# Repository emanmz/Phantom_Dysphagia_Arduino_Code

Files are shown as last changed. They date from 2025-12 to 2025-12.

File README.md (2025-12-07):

## ⚙️ README: Linear Actuator Control Code

This README provides an overview and instructions for the Arduino code used to control two stepper-motor-driven linear actuators. This is includes multiple files:
Linear_Actuator_Code_2_Change_negative_or_positive
Linear_Actuator_Code_with_Calibration
Rail_to_Arduino_DAQ
Adams_Apple_Movement.py
Linear_Regression.py

## 1st **Code File:** (Implied: `Linear_Actuator_Code_2_Change_negative_or_positive.ino`)

-----

## ⚠️ WARNING: Free Use / Uncalibrated Mode

This code is designed for "free use," allowing absolute positioning of the actuators without applying calibration coefficients.

  * **DANGER:** Use caution. The position commands directly translate to motor steps, meaning if the physical system is not homed or if the motor loses steps, the reported position will be incorrect, potentially leading to the actuator hitting its physical end stops.
  * **Recommendation:** Only use this code if you fully understand the mechanics and stepper motor operation.

-----

## 📌 Actuator & Axis Definitions

This system uses standard CNC-style axis naming conventions:

| Axis | Actuator | Movement | Pins | Position Range |
| :--- | :--- | :--- | :--- | :--- |
| **Z** | Horizontal | Forward & Backwards | `dirPinH` (2), `stepPinH` (3) | **Negative and Positive** |
| **Y** | Vertical | Up & Down | `dirPinV` (9), `stepPinV` (8) | **Negative and Positive** |

-----

## 🚀 How to Use (Serial Interface)

The code runs in a continuous loop, monitoring the Serial Monitor for position and speed commands.

### 1\. Startup

1.  Connect the Arduino to the PC and open the **Serial Monitor** at **9600 baud**.
2.  The system will output: `Ready. Send input as: z_mm,z_mmps,vert_mm,vert_mmps`

### 2\. Sending Commands

Commands must be sent in the following comma-separated format:

```
z_mm,z_mmps,vert_mm,vert_mmps
```

| Parameter | Description | Units | Range |
| :--- | :--- | :--- | :--- |
| **`z_mm`** | Target absolute position for the **Z (Horizontal)** axis. | mm | Constrained by `min_position_mm_z` (e.g., -5.0) and `max_position_mm_z` (e.g., 25.0). |
| **`z_mmps`** | Desired speed for the **Z (Horizontal)** axis. | mm/s | Constrained to **5.0 to 25.0 mm/s**. |
| **`vert_mm`** | Target absolute position for the **Y (Vertical)** axis. | mm | Constrained by `min_position_mm_vertical` (e.g., -5.0) and `max_position_mm_vertical` (e.g., 100.0). |
| **`vert_mmps`**| Desired speed for the **Y (Vertical)** axis. | mm/s | Constrained to **20.0 to 80.0 mm/s**. |

**Example Command:**

To move the Z-axis to 10.0 mm at 15 mm/s and the Vertical (Y) axis to 50.0 mm at 40 mm/s, send:

```
10.0,15,50.0,40
```

-----

## 🛠️ Key Code Settings

The main configurable values are located at the top of the file under `PIN & SETTINGS`.

### Horizontal (Z) Settings

| Constant | Value | Description |
| :--- | :--- | :--- |
| `steps_per_mm_horizontal` | `613.50` | The physical steps required for 1 mm of Z-axis travel. **Crucial for accuracy.** |
| `max_position_mm_z` | `25.00` | Max positive position allowed for Z (soft limit). |
| `min_position_mm_z` | `-5.0` | Max negative position allowed for Z (soft limit). |

### Vertical (Y) Settings

| Constant | Value | Description |
| :--- | :--- | :--- |
| `steps_per_mm_vertical` | `555.56` | The physical steps required for 1 mm of Y-axis travel. **Crucial for accuracy.** |
| `max_position_mm_vertical` | `100.0` | Max positive position allowed for Y (soft limit). |
| `min_position_mm_vertical` | `-5.0` | Max negative position allowed for Y (soft limit). |

-----

## 💻 Core Functions

### `moveBoth(float zMM, float zSpeed_mmps, float vertMM, float vertSpeed_mmps)`

  * **Purpose:** Moves both actuators simultaneously to the absolute target positions specified by `zMM` and `vertMM`.
  * **Logic:**
    1.  Calculates the required **target steps** (`targetH`, `targetV`) by multiplying the input `mm` by the respective `steps_per_mm`.
    2.  Calculates the **delta steps** (`deltaH`, `deltaV`) needed from the current position.
    3.  Determines the direction (`dirH`, `dirV`) based on whether the target step count is higher or lower than the current step count.
    4.  Calculates the **step delay** from the input speed (`mm/s`).
    5.  Steps both motors in a blocking `while` loop until both reach their respective targets.
    6.  Updates the global position variables (`currentPositionStepsH`, `currentPositionStepsV`).

## 2nd Code: Linear_Actuator_Code_with_Calibration Calibrated 2-Axis Actuator Control with LVDT

This code is an Arduino sketch designed for **precise, closed-loop positioning** of two stepper motor actuators (Horizontal/Z and Vertical/Y) by applying **calibration coefficients** derived from an **LVDT (Linear Variable Differential Transformer)** sensor.

-----

## ⚠️ Operation Mode

This code is designed for laboratory or experimental use where the relationship between the commanded motor travel and the real-world measured travel must be continuously corrected.

  * **Axis Naming:**

      * **Horizontal (H) Actuator** = **Z-Axis** (Forward/Backward)
      * **Vertical (V) Actuator** = **Y-Axis** (Up/Down)

  * **Core Function:** It performs two main tasks:

    1.  **Calibration:** Runs routines (`calibrate_z`, `calibrate_y`) to determine the correction factors (slope and offset) between commanded motor movement and the actual movement measured by the LVDT.
    2.  **Movement:** Uses the calculated correction factors to convert a **Desired Real-World position** (`realHorizMM`) into the **necessary Commanded Motor Steps**.

-----

## 🛠️ Key Components & Setup

### 1\. Actuators and Kinematics

| Axis | Pin Settings | Max Position | Steps/mm |
| :--- | :--- | :--- | :--- |
| **Z** (Horizontal) | `dirPinH` (2), `stepPinH` (3) | `25.00 mm` | `613.50` |
| **Y** (Vertical) | `dirPinV` (9), `stepPinV` (8) | `100.0 mm` | `555.56` |

### 2\. LVDT Sensor (Measurement)

The LVDT measures real-world displacement and is critical for calibration.

| Setting | Value | Description |
| :--- | :--- | :--- |
| `LVDT_PIN` | `A0` | Analog Pin for LVDT input (0-1023 bits). |
| `CAL_LVDT_SLOPE_MM_PER_BIT` | `-0.00518` | Slope ($m$) from the LVDT's initial characterization: $mm = m \cdot bit + b$. |
| `CAL_LVDT_INTERCEPT_MM` | `4.84308` | Intercept ($b$) from the LVDT's initial characterization. |
| `LVDT_MAX/MIN_DEFLECTION` | `3.7` / `1.7` | Values used to **filter out bad/unstable readings** during data collection. |

### 3\. Calibration Coefficients

These values are updated after running the calibration routines (`Z` or `Y`). They define the final correction formula:

$$
\text{Real mm} = \text{Slope} \cdot \text{Commanded mm} + \text{Offset}
$$

| Axis | Variable | Initial Value |
| :--- | :--- | :--- |
| **Z** | `cal_slope_z` | `0` |
| **Z** | `cal_offset_z` | `-0.776723` |
| **Y** | `cal_slope_Y` | `1.639743` |
| **Y** | `cal_offset_Y` | `0` |

-----

## ⌨️ Serial Commands

All interaction is done via the **Serial Monitor** at **9600 baud**.

### 1\. Calibration

To initiate a calibration routine:

  * **Z-Axis (Horizontal):** Type `Z`
  * **Y-Axis (Vertical):** Type `Y`

The code will prompt you to confirm with `Ready` before starting the movement and data collection process.

### 2\. Movement (Using Calibration)

To move the actuators to a **real-world desired position** after calibration:

1.  Type `Move` (This simply prints the command format).
2.  Send the position and speed command in the following format:

<!-- end list -->

```
horiz_mm,horiz_speed,vert_mm,vert_speed
```

| Parameter | Description |
| :--- | :--- |
| `horiz_mm` | **Desired Real-World Z position (mm)**. |
| `horiz_speed` | **Z-Axis speed (mm/s)**. |
| `vert_mm` | **Desired Real-World Y position (mm)**. |
| `vert_speed` | **Y-Axis speed (mm/s)**. |

The `moveBoth` function will automatically apply the calculated **`cal_slope`** and **`cal_offset`** to determine the actual steps needed to hit the `realHorizMM` target.

-----

## ⚙️ Core Functionality

### **Core Functionality: `moveBoth(...)`**

* **Correction:** It inverts the calibration equation to find the required motor command using the formula above.
* **Execution:** The motor is then commanded to move to the calculated **Commanded mm** position using a non-blocking step algorithm.

### `moveBoth(...)`

This function handles the main movement using the calibration coefficients.

### **Inverse Calibration Formula**

The `moveBoth` function uses this formula to calculate the necessary motor command:

$$
\text{Commanded mm} = \frac{\text{Desired Real mm} - \text{Offset}}{\text{Slope}}
$$

  * **Execution:** The motor is then commanded to move to the `Commanded mm` position using a non-blocking step algorithm.

### `readLVDT_mm()`

Reads the LVDT sensor, averages **200 analog samples**, applies the LVDT's intrinsic calibration constants, and returns the measured displacement in mm. It uses the `LVDT_MAX/MIN_DEFLECTION` limits to return a sentinel value of `-999.0` for noisy or invalid readings, ensuring only quality data is used for the actuator calibration.

### `linearRegression(...)`

Performs a standard linear fit to calculate the **slope** and **intercept (offset)** based on the collected data points (Commanded vs. Measured positions). This result is stored in the global `cal_slope` and `cal_offset` variables.

This system is a sophisticated **Data Acquisition (DAQ)** platform that controls two linear actuators using pre-determined calibration coefficients and streams real-time LVDT sensor data back to a controlling **Python script** for logging and analysis.

---

#### 3rd & 4th **Code Files:** Calibrated 2-Axis Motion and Data Streaming (Rail\_to\_Arduino\_DAQ & Adams\_Apple\_Movement)

This project consists of two linked files:

1.  **Arduino Code (Rail\_to\_Arduino\_DAQ):** Controls the stepper motors, reads the LVDT, applies calibration corrections for movement, and streams real-time movement data.
2.  **Python Code (`Adams_Apple_Movement.py`):** Acts as the **Host Controller** to send movement commands to the Arduino and captures the streaming data into a CSV log file.

---

## 📌 Actuator & Axis Definitions

This system uses a horizontal actuator (Z) and a vertical actuator (Y).

| Axis | Actuator | Movement | Max Position (Commanded) |
| :--- | :--- | :--- | :--- |
| **H / X-Axis** | Horizontal | Forward & Backwards | `25.00 mm` |
| **V / Y-Axis** | Vertical | Up & Down | `100.0 mm` |

### Calibration Model

The core of the movement logic is the **inverse calibration** applied in the `moveBoth` function:

$$
\text{Commanded mm} = \frac{\text{Desired Real mm} - \text{Offset}}{\text{Slope}}
$$

This equation correctly solves for the necessary motor command to achieve the $\text{Desired Real mm}$ based on the calculated $\text{Slope}$ and $\text{Offset}$ coefficients.
| Axis | Coefficient | Value | Description |
| :--- | :--- | :--- | :--- |
| **X (H)** | `cal_slope_X` | `0.900650` | Slope correction for horizontal travel. |
| **X (H)** | `cal_offset_X` | `-0.776723` | Offset correction for horizontal travel. |
| **Y (V)** | `cal_slope_Y` | `1.639743` | Slope correction for vertical travel. |
| **Y (V)** | `cal_offset_Y` | `-1.543572` | Offset correction for vertical travel. |

---

## ⚡️ Arduino Sketch: Motion Control & Data Streaming

The Arduino sketch focuses on executing a movement, applying calibration, and streaming the resulting data over the serial port.

### Key Functionality

1.  **Movement (`moveBoth`):** Accepts **Desired Real-World MM** values, converts them to the required **Commanded Motor MM** using the calibration coefficients, and executes the movement by calculating the necessary steps and timing delays.
2.  **Real-Time Logging:** While the motors are stepping, data is logged every $\mathbf{50}$ **steps** (`LOG\_INTERVAL\_STEPS`). Each line streams:
    * Time (ms)
    * Current Steps (H & V)
    * Commanded MM (H & V, based on steps)
    * Estimated Real MM (H & V, based on calibration)
    * Real LVDT Reading (mm)
3.  **End-of-Move Summary:** After the motion is complete and the LVDT is sampled at the final position, a summary block is printed, demarcated by `#MOVE_CALC_DATA_START` and `#MOVE_CALC_DATA_END`. This allows the Python script to easily isolate the final, definitive data points for a single move.
4.  **Homing:** After every `moveBoth` command, the code immediately calls `moveBoth_Without_Calib(0, horizSpeed, 0, vertSpeed)` to **return the actuators to the zero position**.

---

## 🐍 Python Host Script: Data Acquisition (DAQ)

The Python script manages the experiment sequence, sends commands, and captures all serial output, separating the streaming data from the summary data.

### Configuration

* **`ARDUINO_PORT`:** Must be changed to match your Arduino's serial port (e.g., `'COM3'` on Windows, `'/dev/ttyACM0'` on Linux/Mac).
* **`OUTPUT_CSV_FILE`:** The file name where all real-time stream data will be logged (e.g., `'movement_log6.csv'`).
* **`MOVEMENT_PLAN`:** A list of moves to execute in sequence. Each element is `[realHorizMM, horizSpeed_mmps, realVertMM, vertSpeed_mmps]`.

### Data Logging Logic

The script uses a **state machine** to handle the varying output from the Arduino:

1.  **Stream Data:** All comma-separated lines *outside* the summary block are treated as real-time movement data and are written directly to the CSV file.
2.  **Summary Block:** Lines between `#MOVE_CALC_DATA_START` and `#MOVE_CALC_DATA_END` are read and ignored in the main CSV stream, as they serve as an end-of-move marker for more targeted data extraction if needed.
3.  **Sequence Completion:** The script waits until the Arduino prints a final position report (`"Current Pos V: "`) to confirm the entire sequence (move out + return to zero) is complete before proceeding to the next move in `MOVEMENT_PLAN`.

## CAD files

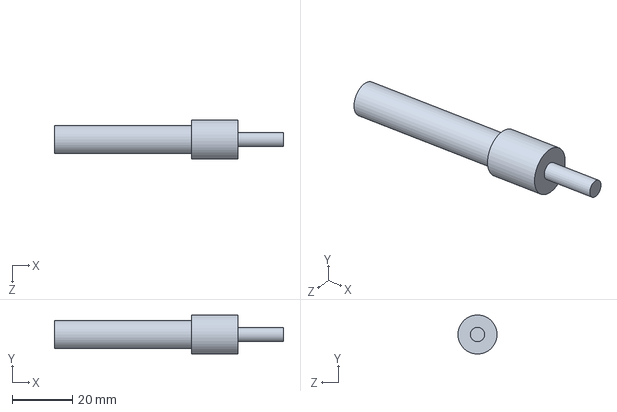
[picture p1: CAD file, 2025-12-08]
Current LVDT.SLDPRT
75.9 x 12.9 x 13.0 mm

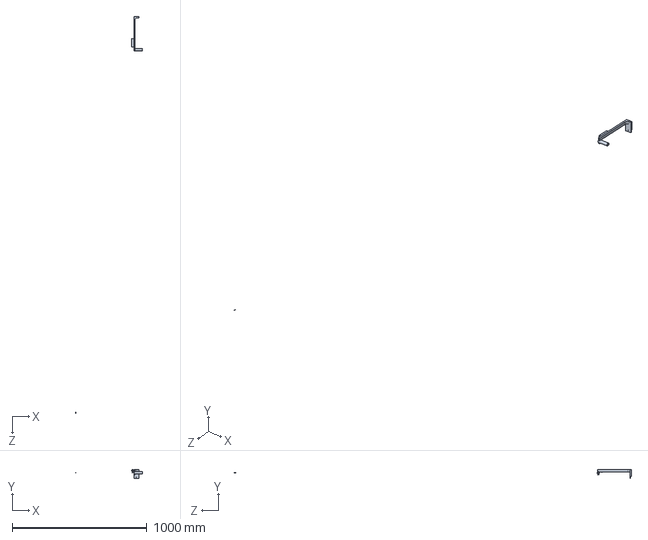
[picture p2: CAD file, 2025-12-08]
SensorRig.SLDPRT
493.7 x 66.8 x 2942.1 mm

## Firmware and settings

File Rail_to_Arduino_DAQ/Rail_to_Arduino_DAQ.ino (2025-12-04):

// =============================================================
// PIN & SETTINGS
// =============================================================

// Vertical actuator (100mm stroke)
#define dirPinV 9
#define stepPinV 8
const float steps_per_mm_vertical = 555.56;
const float max_position_mm_vertical = 100.0;
long currentPositionStepsV = 0;

// Horizontal actuator (13.04 mm stroke)
#define dirPinH 2
#define stepPinH 3
const float steps_per_mm_horizontal = 613.50;
const float max_position_mm_horizontal = 25.00;
long currentPositionStepsH = 0;


// =============================================================
// LVDT CALIBRATION
// LVDT connected to Analog Pin A0
// =============================================================
const int LVDT_PIN = A0;
const float CAL_LVDT_SLOPE_MM_PER_BIT = -0.00518; // m (mm/bit)
const float CAL_LVDT_INTERCEPT_MM = 4.84308; // b (mm)

// LVDT Filtering Limits
const float LVDT_MAX_DEFLECTION = 3.7; 
const float LVDT_MIN_DEFLECTION = 1.7; 
const float CAL_Y_MAX_MM = 2.5; 

// =============================================================
// CALIBRATION COEFFICIENTS
// These map Commanded MM (calculated from steps) to Real MM (estimated position)
// Real_MM = Commanded_MM * Slope + Offset
// Commanded_MM = (Real_MM - Offset) / Slope
// =============================================================
float cal_slope_X = 0.900650; 
float cal_offset_X = -0.776723;
float cal_slope_Y = 1.639743; 
float cal_offset_Y = -1.543572;

// =============================================================
// FUNCTION HEADERS
// =============================================================
void moveBoth(float realHorizMM, float horizSpeed_mmps,
              float realVertMM, float vertSpeed_mmps);
void moveBoth_Without_Calib(float horizMM, float horizSpeed_mmps, float vertMM, float vertSpeed_mmps);
float readLVDT_mm();


// =============================================================
// GLOBAL LOGGING FLAG
// Used to print the header only once before streaming starts.
bool hasPrintedHeader = false;
const int LOG_INTERVAL_STEPS = 50; 

// =============================================================
// SETUP
// =============================================================
void setup() {
  pinMode(stepPinV, OUTPUT);
  pinMode(dirPinV, OUTPUT);
  pinMode(stepPinH, OUTPUT);
  pinMode(dirPinH, OUTPUT);
  pinMode(LVDT_PIN, INPUT); 

  Serial.begin(9600);
  delay(300);

  Serial.println("Ready. Use 'horizMM,horizSpeed,vertMM,vertSpeed' command.");
}


// =============================================================
// LOOP (MODIFIED FOR PYTHON)
// =============================================================
void loop() {
  if (!Serial.available()) return;

  String input = Serial.readStringUntil('\n');
  input.trim();
  
  // --- direct movement (triggered by the Python script or manual input) ----
  if (input.indexOf(',') != -1) {
    int p1 = input.indexOf(',');
    int p2 = input.indexOf(',', p1 + 1);
    int p3 = input.indexOf(',', p2 + 1);
    
    // Check for all three commas
    if (p1 < 0 || p2 < 0 || p3 < 0) {
      Serial.println("Invalid format. Expected: horizMM,horizSpeed,vertMM,vertSpeed");
      return;
    }

    float horizMM = input.substring(0, p1).toFloat();
    float horizSpeed = input.substring(p1 + 1, p2).toFloat();
    float vertMM = input.substring(p2 + 1, p3).toFloat();
    float vertSpeed = input.substring(p3 + 1).toFloat();

    // safe speeds (constraints ensure movement is within reasonable limits)
    horizSpeed = constrain(horizSpeed, 5.0, 25.0);
    vertSpeed = constrain(vertSpeed, 20.0, 80.0);

    moveBoth(horizMM, horizSpeed, vertMM, vertSpeed);

    Serial.println("Returning to zero...");
    moveBoth_Without_Calib(0, horizSpeed, 0, vertSpeed);
  }
}


// =============================================================
// LVDT READING FUNCTION
// =============================================================
float readLVDT_mm() {
  long sum_bits = 0;
  // Increase sampling for better average (e.g., 200 samples)
  for (int i = 0; i < 200; i++) sum_bits += analogRead(LVDT_PIN); 
  float avg_bit = sum_bits / 200.0;
  
  // Apply LVDT calibration: mm_measured = m * avg_bit + b
  float mm_measured = CAL_LVDT_SLOPE_MM_PER_BIT * avg_bit + CAL_LVDT_INTERCEPT_MM;
  
  
  return mm_measured;
}

// =============================================================
// MOVE FUNCTION (USES CALIBRATION) (REAL-TIME STREAMING)
// =============================================================
void moveBoth(float realHorizMM, float horizSpeed_mmps,
              float realVertMM, float vertSpeed_mmps)
{
  // 1. Convert REAL (Desired) MM to COMMANDED MM using inverse calibration
  float horizMM_cmd_target = (realHorizMM - cal_offset_X) / cal_slope_X;
  float vertMM_cmd_target = (realVertMM - cal_offset_Y) / cal_slope_Y;
  
  // 2. Constrain Commanded MM to physical limits
  horizMM_cmd_target = constrain(horizMM_cmd_target, 0.0, max_position_mm_horizontal);
  vertMM_cmd_target = constrain(vertMM_cmd_target, 0.0, max_position_mm_vertical);

  // 3. Convert Commanded MM to Target Steps
  long targetH = round(horizMM_cmd_target * steps_per_mm_horizontal);
  long targetV = round(vertMM_cmd_target * steps_per_mm_vertical);
  
  // 4. Calculate steps to move (delta) and direction (dir)
  long totalDeltaH = abs(targetH - currentPositionStepsH);
  long totalDeltaV = abs(targetV - currentPositionStepsV);

  bool dirH = (targetH > currentPositionStepsH);
  bool dirV = (targetV > currentPositionStepsV);

  // Horizontal direction is FLIPPED (LEFT/Positive MM = LOW)
  digitalWrite(dirPinH, dirH ? LOW : HIGH);
  // Vertical direction (DOWN/Positive MM = LOW) 
  digitalWrite(dirPinV, dirV ? LOW : HIGH);

  // 5. Calculate step delay (micro-seconds) from speed (mm/s)
  int delayH = max(80, int(1000000.0 / (horizSpeed_mmps * steps_per_mm_horizontal)));
  int delayV = max(80, int(1000000.0 / (vertSpeed_mmps * steps_per_mm_vertical)));

  // 6. Perform the movement (Blocking)
  long sH = 0; // Steps executed for Horizontal in this move
  long sV = 0; // Steps executed for Vertical in this move
  int log_counter = 0; // Counter for step logging interval
  
  // Initial Header Print (Only print header once at the start of the first movement)
  if (!hasPrintedHeader) {
    // UPDATED HEADER with Commanded MM and Real MM for both axes
    Serial.println("Time_ms,Steps_H,Commanded_H_mm,Real_H_mm,Steps_V,Commanded_V_mm,Real_V_mm,LVDT_Output_mm"); 
    hasPrintedHeader = true;
  }
  
  // Loop until both actuators have reached their delta steps
  while (sH < totalDeltaH || sV < totalDeltaV) {
    
    // Horizontal Stepping
    if (sH < totalDeltaH) {
      digitalWrite(stepPinH, HIGH); 
      delayMicroseconds(delayH);
      digitalWrite(stepPinH, LOW); 
      delayMicroseconds(delayH);
      sH++;
    }

    // Vertical Stepping
    if (sV < totalDeltaV) {
      digitalWrite(stepPinV, HIGH); 
      delayMicroseconds(delayV);
      digitalWrite(stepPinV, LOW); 
      delayMicroseconds(delayV);
      sV++;
    }
    
    // --- REAL-TIME LVDT SAMPLING AND STREAMING ---
    // Log data every LOG_INTERVAL_STEPS (50 steps)
    if (log_counter >= LOG_INTERVAL_STEPS) {
      unsigned long current_time_ms = millis();
      float current_lvdt_mm = readLVDT_mm();
      
      // Calculate current absolute position in steps
      long current_steps_H = currentPositionStepsH + (dirH ? sH : -sH);
      long current_steps_V = currentPositionStepsV + (dirV ? sV : -sV);

      // Calculate the Commanded MM (based on physical steps)
      float current_cmd_mm_H = current_steps_H / steps_per_mm_horizontal;
      float current_cmd_mm_V = current_steps_V / steps_per_mm_vertical;

      // Calculate the Estimated Real MM (based on calibration)
      float current_real_mm_H = current_cmd_mm_H * cal_slope_X + cal_offset_X;
      float current_real_mm_V = current_cmd_mm_V * cal_slope_Y + cal_offset_Y; // The one to compare with LVDT
      
      // Stream the data line (8 columns now)
      Serial.print(current_time_ms); Serial.print(",");
      Serial.print(current_steps_H); Serial.print(","); 
      Serial.print(current_cmd_mm_H, 6); Serial.print(","); // NEW
      Serial.print(current_real_mm_H, 6); Serial.print(","); // NEW
      Serial.print(current_steps_V); Serial.print(","); 
      Serial.print(current_cmd_mm_V, 6); Serial.print(","); // NEW
      Serial.print(current_real_mm_V, 6); Serial.print(","); // NEW
      Serial.print(current_lvdt_mm, 6); Serial.println();
      
      log_counter = 0; // Reset counter
    }
    log_counter++; // Increment counter for every step cycle
  }

  // 7. Update current position (steps 6 & 7 from original logic)
  currentPositionStepsH = targetH;
  currentPositionStepsV = targetV;
  
  // 8. FINAL DATA LOGGING (Using original markers for Python compatibility)
  
  // Capture final time and LVDT reading at the absolute stop point
  unsigned long time_at_stop_ms = millis();
  float final_lvdt_mm = readLVDT_mm();
  
  // --- FINAL POSITION LOG (Uses markers for Python to capture the 'official' result) ---
  // This section remains the same as it already captures the required calibration parameters.
  Serial.println("\n#MOVE_CALC_DATA_START");
  Serial.println("Time_ms,Desired_Horiz_MM,Commanded_Horiz_MM,X_Slope,X_Offset,Desired_Vert_MM,Commanded_Vert_MM,Y_Slope,Y_Offset,LVDT_Output");
  
  // Data Line
  Serial.print(time_at_stop_ms); Serial.print(","); 
  Serial.print(realHorizMM, 6); Serial.print(",");
  Serial.print(horizMM_cmd_target, 6); Serial.print(",");
  Serial.print(cal_slope_X, 6); Serial.print(",");
  Serial.print(cal_offset_X, 6); Serial.print(",");
  
  Serial.print(realVertMM, 6); Serial.print(",");
  Serial.print(vertMM_cmd_target, 6); Serial.print(",");
  Serial.print(cal_slope_Y, 6); Serial.print(",");
  Serial.print(cal_offset_Y, 6); Serial.print(",");
  
  Serial.print(final_lvdt_mm, 6);
  Serial.println(); 

  
  Serial.println("#MOVE_CALC_DATA_END\n");
  // ------------------------------------------------------------

  Serial.println(" ");
  Serial.print("Current Pos H: ");
  Serial.println(currentPositionStepsH);
  Serial.print("Current Pos V: ");
  Serial.println(currentPositionStepsV);
}

void moveBoth_Without_Calib(float horizMM, float horizSpeed_mmps, float vertMM, float vertSpeed_mmps) {
  // Target steps can be negative if horizMM is negative
  long targetH = horizMM * steps_per_mm_horizontal;
  long targetV = vertMM * steps_per_mm_vertical;

  // delta is always the absolute step difference needed
  long deltaH = abs(targetH - currentPositionStepsH);
  long deltaV = abs(targetV - currentPositionStepsV);

  // dirH/dirV is true if moving to a higher (more positive) step count
  bool dirH = targetH > currentPositionStepsH;
  bool dirV = targetV > currentPositionStepsV;
  
  // Set directions
  // Horizontal direction is FLIPPED (LEFT/Positive MM = LOW)
  digitalWrite(dirPinH, dirH ? LOW : HIGH);
  // Vertical direction (DOWN/Positive MM = LOW) 
  digitalWrite(dirPinV, dirV ? LOW : HIGH); 

  // Calculate step delay (micro-seconds) from speed (mm/s)
  int delayH = (int)(1000000.0 / (horizSpeed_mmps * steps_per_mm_horizontal));
  int delayV = (int)(1000000.0 / (vertSpeed_mmps * steps_per_mm_vertical));
  // Ensure minimum delay (max speed limit)
  delayH = max(80, delayH);
  delayV = max(80, delayV);

  long stepsH = 0, stepsV = 0;

  // Core movement loop
  while (stepsH < deltaH || stepsV < deltaV) {
    if (stepsH < deltaH) {
      digitalWrite(stepPinH, HIGH);
      delayMicroseconds(delayH);
      digitalWrite(stepPinH, LOW);
      delayMicroseconds(delayH);
      stepsH++;
    }

    if (stepsV < deltaV) {
      digitalWrite(stepPinV, HIGH);
      delayMicroseconds(delayV);
      digitalWrite(stepPinV, LOW);
      delayMicroseconds(delayV);
      stepsV++;
    }
  }

  // Update current position to the new (potentially negative) target
  Serial.println(" ");
  currentPositionStepsH = targetH;
  Serial.print("Current Pos H: ");
  Serial.println(currentPositionStepsH);
  currentPositionStepsV = targetV;
  Serial.print("Current Pos V: ");
  Serial.println(currentPositionStepsV);
}

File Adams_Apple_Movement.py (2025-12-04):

import serial
import time
import csv

# --- Configuration ---
# Windows: 'COM3', 'COM4', etc.
# Mac/Linux: '/dev/ttyACM0' or '/dev/ttyUSB0' or similar (often starts with /dev/tty.)
ARDUINO_PORT = '/dev/cu.usbmodem141401'  # <-- CHANGE THIS TO YOUR ARDUINO PORT
BAUD_RATE = 9600
OUTPUT_CSV_FILE = 'movement_log6.csv'

# Define a list of movements to execute (in mm and mm/s)
# Format: [realHorizMM, horizSpeed_mmps, realVertMM, vertSpeed_mmps]
MOVEMENT_PLAN = [
    [0.0, 10, 0.5, 40]]

# --- Main Logic ---

def run_movements_and_log():
    try:
        # 1. Establish Serial connection
        ser = serial.Serial(ARDUINO_PORT, BAUD_RATE, timeout=5)
        print(f"Connected to Arduino on {ARDUINO_PORT}")
        time.sleep(2) # Give Arduino time to reset and initialize Serial

        # Wait for "Ready." message from Arduino before sending commands
        while True:
            line = ser.readline().decode('utf-8', errors='ignore').strip()
            if "Ready" in line:
                print(f"Arduino acknowledged: {line}")
                break
        
        # 2. Prepare CSV file
        with open(OUTPUT_CSV_FILE, 'w', newline='') as csvfile:
            log_writer = csv.writer(csvfile)
            
            # The Arduino will print the stream header once globally.
            header_written = False
            
            # Flag to ignore the specific final summary block output
            is_in_summary_block = False 

            for i, move in enumerate(MOVEMENT_PLAN):
                # Construct the command string: "horizMM,horizSpeed,vertMM,vertSpeed\n"
                command = f"{move[0]},{move[1]},{move[2]},{move[3]}\n"
                print(f"\n--- Running Move {i+1}: {command.strip()} ---")
                
                # Send command
                ser.write(command.encode())
                
                # 3. Read the Serial response continuously until the move sequence finishes
                start_time = time.time()
                move_sequence_complete = False
                
                # We expect the full sequence (move to target + return to zero) 
                # to take no more than 30 seconds.
                while time.time() - start_time < 30: 
                    line = ser.readline().decode('utf-8', errors='ignore').strip()
                    
                    if not line:
                        continue
                    
                    # --- State Machine for Summary Block ---
                    if line == "#MOVE_CALC_DATA_START":
                        is_in_summary_block = True
                        continue
                    
                    if line == "#MOVE_CALC_DATA_END":
                        is_in_summary_block = False
                        # We also skip the next line, which is usually a blank line
                        ser.readline() 
                        continue
                    
                    # --- State Detection for Sequence End ---
                    # The Arduino prints "Current Pos V: " at the end of each moveBoth call.
                    if line.startswith("Current Pos V:"):
                        print(f"[Arduino]: {line}")
                        # We check if the next command in the loop should run 
                        # (i.e., this move is done)
                        if "Returning to zero" not in line: 
                            move_sequence_complete = True
                            break 
                    
                    # --- Data Logging Logic ---
                    # We check if the line is not empty, not a summary block, and contains commas (is data)
                    if not is_in_summary_block and ',' in line:
                        # Stream Header: "Time_ms,Steps_H,Steps_V,LVDT_Output_mm"
                        if line.startswith("Time_ms,Steps_H"):
                            if not header_written:
                                log_writer.writerow(line.split(','))
                                header_written = True
                        
                        # Data Line (Starts with a number and has commas)
                        elif header_written:
                            try:
                                # Attempt to cast the first element to float to confirm it's a data row
                                float(line.split(',')[0]) 
                                log_writer.writerow(line.split(','))
                            except ValueError:
                                # It's a line with commas but not data (e.g., error message)
                                print(f"[Arduino]: {line}") 
                        
                    # Print all other non-data, non-marker lines (debug messages)
                    elif not is_in_summary_block:
                         print(f"[Arduino]: {line}") 

                if not move_sequence_complete:
                    print(f"Warning: Move sequence {i+1} timed out or did not complete cleanly.")


    except serial.SerialException as e:
        print(f"\nERROR: Could not connect to port {ARDUINO_PORT}. Please check the port name and ensure the Arduino IDE Serial Monitor is closed.")
        print(f"Detail: {e}")
    except Exception as e:
        print(f"\nAn unexpected error occurred: {e}")
    finally:
        if 'ser' in locals() and ser.is_open:
            ser.close()
            print("\nSerial connection closed.")
            print(f"Data saved to {OUTPUT_CSV_FILE}")

if __name__ == "__main__":
    run_movements_and_log()

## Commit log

2025-12-02 fixed issue with x calibration
    [Linear_Actuator_Code_2_Change_negative_or_positive.ino, Linear_Actuator_Code_with_Calibration.ino]
2025-12-02 y calibration fixing
2025-12-04 more testing files etc etc
    [movement_log.csv, movement_log2.csv, movement_log3.csv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]
2025-12-07 fixed the code yay! lots of comments too so people can read it
    [movement_log.csv, movement_log2.csv, movement_log3.csv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]
2025-12-08 Add files via upload
    cad's
    [Current LVDT.SLDPRT, SensorRig.SLDPRT]
